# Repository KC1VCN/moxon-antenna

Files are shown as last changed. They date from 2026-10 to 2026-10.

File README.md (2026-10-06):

# 10-Meter Band Moxon Antenna

## Introduction

A Moxon antenna is a two-element beam antenna that uses enhanced capacitive coupling between the driven and parasitic elements. This coupling is achieved by bending the ends of both elements 90&#176; toward each other to form a rectangle. Hence, the antenna is also commonly referred to as a "Moxon Rectangle." Compared with a 2-element Yagi, the Moxon antenna has nearly 25% less width while providing nearly the same amount of gain and an excellent front-to-back ratio. Its input impedance is also naturally close to 50 Ohm. Typically, the bent ends of the elements are connected with insulating rods to complete the rectangle. This provides a more rigid structure and improves stability under wind loading.

The Moxon antenna was invented by Les Moxon, G6XN. A substantial amount of literature is available on the Moxon antenna, and several useful references are listed below:

1. Les Moxon, G6XN, *HF Antennas for All Locations*, Second Edition, Radio Society of Great Britain.

2. L. B. Cebik, W4RNL, *Moxon Rectangles and Online Calculator*, https://antenna2.github.io/cebik/content/moxon/moxpage.html

3. L. B. Cebik, W4RNL, *The Moxon Rectangle: A Review*, https://antenna2.github.io/cebik/content/moxon/mox20.html

4. L. B. Cebik, W4RNL, *An Aluminum 2-Element Moxon Rectangle 10m*, https://antenna2.github.io/cebik/content/moxon/mox.html

5. *The ARRL Antenna Book*, Chapter 13: HF Beam Antennas, page 13.32, 25th Edition.

---

## Construction

In this section, the construction of the antenna is described. Throughout the text, letters shown in parentheses refer to the corresponding reference indicators in the figures or the parts list.

A picture of the antenna is shown in Fig. 1. The antenna is constructed using telescoping aluminum tubes (*a*1, *a*2, *b*1&ndash;*b*4). The low weight and oxidation resistance of aluminum make it an ideal material for HF antenna construction. The driven (*a*1, *b*1, *b*3) and parasitic (*a*2, *b*2, *b*4) elements are held together by a boom made from a square aluminum tube (*c*).

<figure>
  moxon_antenna
  <figcaption><b>Figure 1:</b> 10-meter Moxon antenna.</figcaption>
</figure>

The dimensions of the constructed antenna are given in Fig. 2. The starting point of the design is the example given in *The ARRL Antenna Book*, 25th Edition, page 13-32. Because the diameters and lengths of the aluminum tubes used here differ from those in the published example, the antenna dimensions were adjusted using a full-wave simulator to obtain acceptable return loss and front-to-back far-field ratio in the 10-meter band.

<figure>
  moxon_dimensions
  <figcaption><b>Figure 2:</b> 10-meter Moxon antenna dimensions.</figcaption>
</figure>

A parts list is provided in the repository in both PDF and spreadsheet formats. Two types of parts are required to construct the antenna: parts that can be purchased from online vendors (e.g., tubes and screws), and parts that must be manufactured. For purchased parts, recommended vendors and part numbers are provided. For manufactured parts, the corresponding CAD file names are listed and can be found in the repository. To assist the builder, recommended online vendors capable of manufacturing these parts are also included.

Construction steps are outlined below:

1. Clean all tubes with 90% isopropyl alcohol to remove grease and dirt.
2. Bend the smaller-diameter tubes (*b*1&ndash;*b*4) to obtain the prescribed tail lengths.
3. Cut one of the 6' long larger-diameter tubes (*a*1) in half using a tube cutter. These sections will be used as the left and right driven elements.
4. Cut slits into one end of the larger-diameter tubes (*a*1) using a hacksaw blade.
5. De-burr and lightly smooth all tube ends using a tubing reamer as needed.
6. Prepare the feed assembly, clamp the larger-diameter tubes (*a*1), attach the assembly to the boom, and connect the balun.
7. Prepare the parasitic-element support assembly, clamp the larger-diameter tube (*a*2), and attach it to the boom.
8. Mark the center of the stiffening rod and insert it inside the driven elements until it is symmetric with respect to the feed point.
9. Insert the smaller-diameter tubes (*b*1&ndash;*b*4) into the larger-diameter tubes (*a*1, *a*2) to obtain the prescribed element lengths.
10. Insert the spacer rods into the tail ends and fasten them to the tubes to obtain the prescribed tail gap.
11. Attach the antenna to a mast at its center of gravity using a mast clamp.

> [!NOTE]
> All tube bends should be made using a lever-style tube bender with a 1.5-inch CLR (Center Line Radius). Care must be taken not to crack or collapse the tubes during bending. Therefore, the use of a good-quality lever-style tube bender is important.
>

> [!TIP]
> It is best to carry out the construction on a good, flat surface such as a garage floor.
>

In the following paragraphs, the construction steps are explained in greater detail.

---

### Antenna Feed

This assembly is where the left and right driven elements are connected to the balun terminals and clamped to the boom. Pictures of the antenna feed section are given in Figs. 3 (with balun) and 4 (close-up).

<figure>
  moxonfeed1
  <figcaption><b>Figure 3:</b> Detailed view of the antenna feed (with balun).</figcaption>
</figure>

The left and right driven elements are mounted to a stainless-steel mounting plate (*f*) using polycarbonate tube clamps (*e*) manufactured by FDM (Fused Deposition Modeling). These clamps are bolted down using pan-head screws (*o*) and stainless-steel compression plates (*d*) to provide uniform pressure across the polycarbonate. The screws must be tightened sufficiently to hold the aluminum tubes straight, but they should not be over-tightened. The plate (*f*) is attached to the boom (*c*) using bracket (*j*) and tap bolts (*n*).

The balun plate (*g*) is first attached to the boom using another bracket (*j*) and flat-head screws (*q*). The flat-head screws used to attach the balun plate to the boom bracket are not visible in the picture because they are located under the balun in the final assembly. To ensure that the balun sits flush on the plate, the plate holes should be chamfered to receive the flat-head screws. The 1:1 balun (*h*) is then attached to plate (*g*) using pan-head screws (*r*).

> [!NOTE]
> The height and spacing of the balun terminals should be selected so that, when the balun is mounted, the terminals align with the aluminum-tube contacts as shown in the figures.
>

> [!NOTE]
> The antenna is mounted with the balun facing downward to prevent the accumulation of snow and ice around the feed structure.
>

A 50" long fiberglass stiffener rod (*m*) is inserted inside the larger aluminum tubes from one of the open ends. This stiffener is placed only inside the larger tubes and does not extend into the smaller end tubes. Its purpose is to provide additional mechanical rigidity and damp mechanical oscillations that may occur under wind loading. The rod should be centered to leave sufficient room for the smaller-diameter tubes to slide inside the larger-diameter tubes.

<figure>
  moxon_feed2
  <figcaption><b>Figure 4:</b> Detailed view of the antenna feed (close-up).</figcaption>
</figure>

Contacts for the aluminum tubes are made using 1/2" wide aluminum strips (*k*) wrapped around the tubes to form loop clamps. Connections between the tube contacts and balun terminals are made using the same 1/2" wide aluminum strips (*l*), which are attached to the loop clamps using pan-head screws (*p*). A PVC dielectric (*i*) is placed between the terminal strips (*l*) to lower the impedance closer to 50 Ohm.

The mounting plate (*f*) is attached to the boom (*c*) using a boom bracket (*j*). The same bracket is also used to attach the balun plate (*g*) to the boom.

> [!NOTE]
> The balun shown in the picture is a custom-designed balun housed in a 4"&#xD7;4"&#xD7;2" PVC NEMA box. Similar baluns can be purchased from online stores, and an example is provided in the parts list.
>

The input UHF connector of the balun should be weatherized using self-fusing silicone tape.

> [!NOTE]
> Self-fusing silicone tape does not contain an adhesive for sticking. It should be stretched during application to activate the tape surface and enable self-fusing. After approximately 24 hours, the tape layers will fuse into a single block, providing waterproof insulation.
>

### Parasitic Element Support

This assembly is where the parasitic element is clamped to the boom. A picture of the parasitic-element support is shown in Fig. 5.

<figure>
  moxon_parasitic
  <figcaption><b>Figure 5:</b> Parasitic element support.</figcaption>
</figure>

To keep the driven- and parasitic-element planes aligned, the same mounting approach used for the driven elements is also used here, with polycarbonate tube clamps (*e*) and the stainless-steel mounting plate (*f*).

A polyethylene square plug (*w*) is placed at both ends of the boom to seal the square tube from the elements.

### Tube Connections

This assembly is where the larger-diameter tubes are connected to the smaller-diameter tubes. A picture of the tube connections is shown in Fig. 6.

<figure>
  moxon_tube
  <figcaption><b>Figure 6:</b> Tube connections.</figcaption>
</figure>

The tubes should be cleaned before assembly to remove grease and residue that could otherwise inhibit a good electrical connection. Note that the excess length of the smaller-diameter tubes can remain inside the larger-diameter tubes.

To facilitate the connections, 3/4" long slits are cut along the connecting ends of the larger-diameter tubes (*a*) to receive the smaller-diameter tubes (*b*). Typically, four slits spaced 90 degrees apart are used. In this case, two slits are also sufficient because the smaller-diameter tubes fit snugly inside the larger-diameter tubes; therefore, little flexing of the slitted ends is required. A hacksaw with a blade thickness of 1/32" can be used to make the cuts. Care must be taken to cut the slits as straight as possible.

> [!TIP]
> Cutting straight slits along the length of the tubes can be tricky. The use of a simple jig is recommended, as is practicing first on a disposable piece of aluminum tube.
>

Stainless-steel hose clamps (*y*) are used to compress tubes (*a*) over the slits and secure tube (*b*). The clamps should be tightened while the antenna is resting on a good, flat surface (e.g., a garage floor) to maintain antenna planarity; otherwise, the tube ends may droop.

> [!NOTE]
> Aluminum flashing that is 1" wide and 1/64" thick can be wrapped over the slits before installing the hose clamps to provide resistance to water intrusion. The hose clamps will compress the flashing and the slitted tube together, squeezing the smaller-diameter tube and forming the electrical connection.
>

### Tube-End Spacers

Tube-end spacers are used to keep the ends of the tubes at a precise distance from each other. They also stabilize the antenna rectangle. A picture of the tube-end spacers is shown in Fig. 7.

<figure>
  moxon_coupling
  <figcaption><b>Figure 7:</b> Tube-end spacers.</figcaption>
</figure>

The ends of the tubes (*b*) should be drilled 1.5" from the edge using a 9/64" drill bit, as shown in the figure. A pre-drilled fiberglass rod (*x*) is then inserted inside the tubes, and machine screws (*s*) are used to hold the tubes and rod together. The separation between the drill holes in the rod should be 5.75"+1.5"+1.5" so that, when the rod is inserted into the aluminum tubes and fastened, the gap between the tube ends is exactly 5.75".

> [!TIP]
> To drill the aluminum tubes and rods accurately and perpendicular to their surfaces, a drill guide can be used.
>

---

## Full-wave Electromagnetic Simulations

It is useful to perform full-wave electromagnetic simulations of the antenna structure before assembling the physical antenna. For this purpose, an open-source 3D finite-element solver called Palace (Parallel Large-scale Computational Electromagnetics) was used (https://awslabs.github.io/palace/stable/). Palace has been developed by the Amazon Web Services (AWS) Center for Quantum Computing. The simulation software was installed on a virtual machine (VM) using Microsoft Azure Cloud Computing Services. The simulations were performed on an E4_v4 virtual machine with 4 vCPUs and 32 GB of RAM. One advantage of cloud computing is that the available compute resources, such as RAM and CPU cores, can be scaled according to model complexity.

<figure>
  moxon_model
  <figcaption><b>Figure 8:</b> Aluminum-tube Moxon antenna model showing the simulation parameters.</figcaption>
</figure>

<table style="width: 600px;">
  <caption></caption>
  <thead>
    <tr>
      <th>A1</th>
      <th>A2</th>
      <th>B</th>
      <th>C</th>
      <th>D</th>
      <th>d1</th>
      <th>d2</th>
    </tr>
  </thead>
  <tbody>
    <tr>
      <td>72"</td>
      <td>38.75"</td>
      <td>19.25"</td>
      <td>5.75"</td>
      <td>27.25"</td>
      <td>0.625"</td>
      <td>0.5"</td>
    </tr>
  </tbody>
</table>

The antenna geometry is generated programmatically using a Python script. The script reads the main antenna parameters (*A*1, *A*2, *B*, *C*, *D*) from an Excel worksheet and generates the corresponding mesh files. The mesh files are then used as input to the Palace simulator. The benefit of using a worksheet is that multiple geometry variations can be listed, allowing a simulation to be submitted simply by specifying a row index and thereby enabling automation. The antenna dimensions were optimized to provide good return loss and front-to-back (F/B) far-field ratio over the desired frequency band.

<figure>
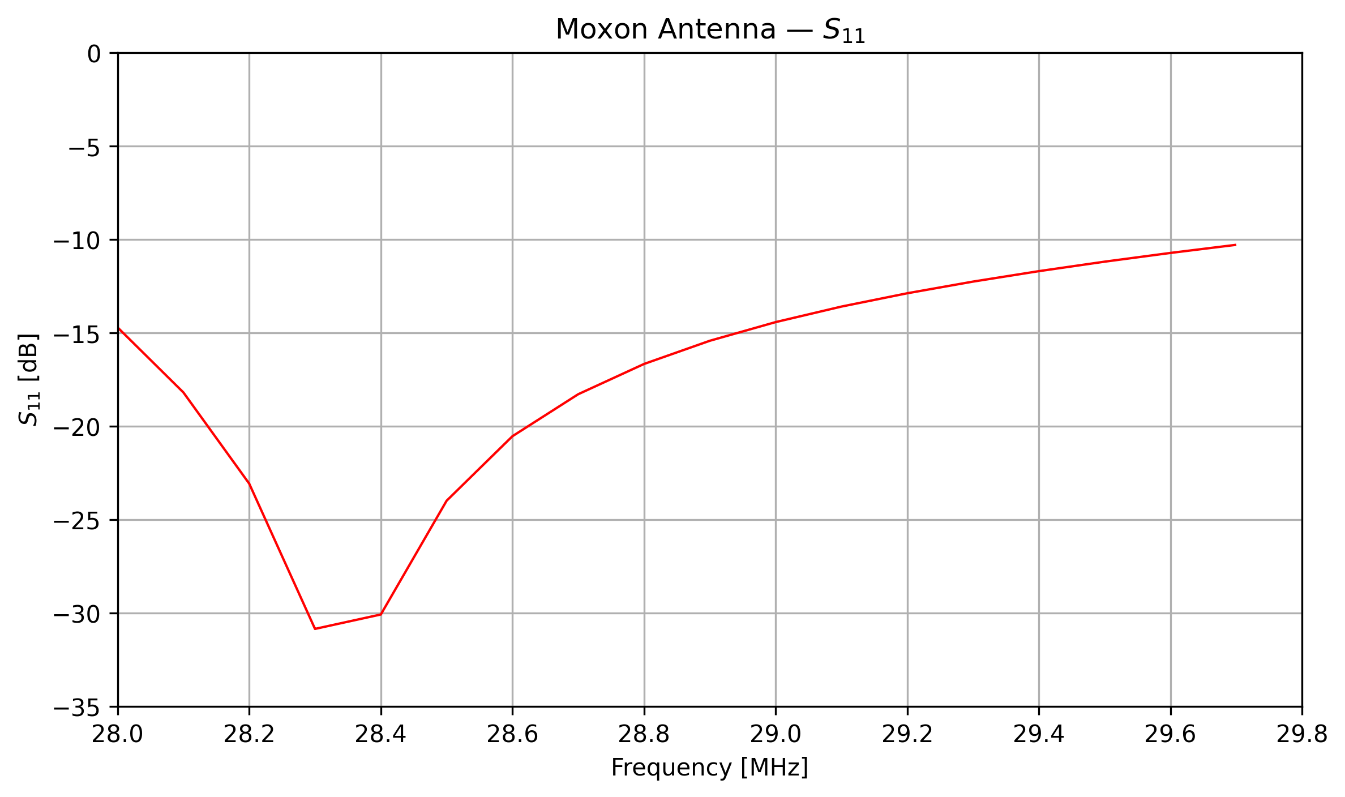
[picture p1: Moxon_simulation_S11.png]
moxon_simulation_S11
  
  <figcaption><b>Figure 9:</b> Simulated S<sub>11</sub> of the 10-meter Moxon antenna.</figcaption>
</figure>

<figure>
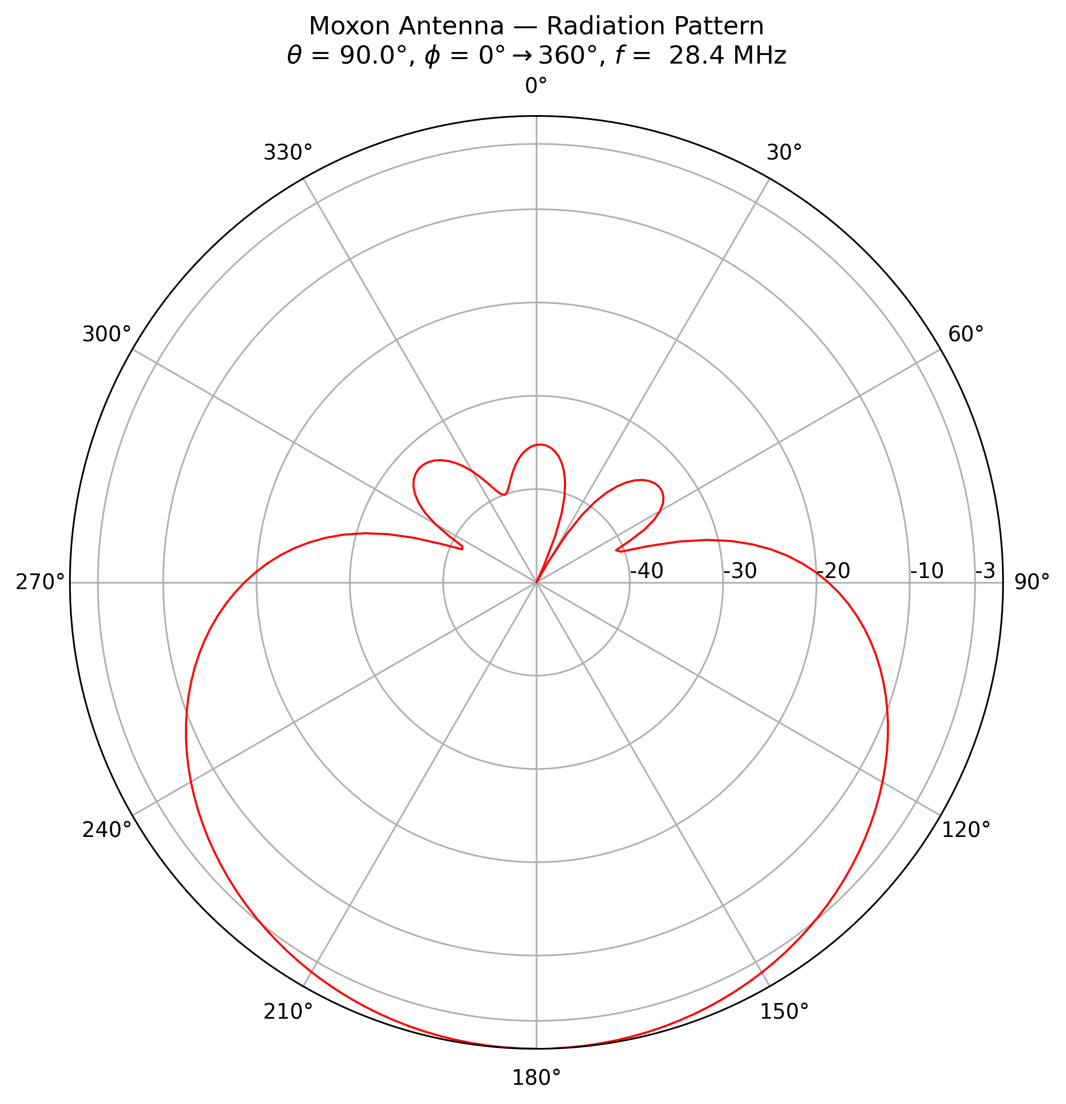
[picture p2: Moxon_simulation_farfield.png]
moxon_simulation_farfield
  
  <figcaption><b>Figure 10:</b> Simulated normalized far-field of the 10-meter Moxon antenna.</figcaption>
</figure>

---

## Measurement Results

The measured return loss (*S*<sub>11</sub>) of the antenna is shown in Fig. 11. The measurements were made using a network analyzer while the antenna was mounted approximately 23 feet above ground on a fiberglass push-up pole. The measurement setup was located at the bottom of the pole. Therefore, the results include the effects of the connecting RG-8X coaxial cable, RF connectors, and the 1:1 balun. A more accurate characterization of the antenna itself could be obtained if the balun were characterized and tuned separately; however, time and resource limitations did not allow this.

<figure>
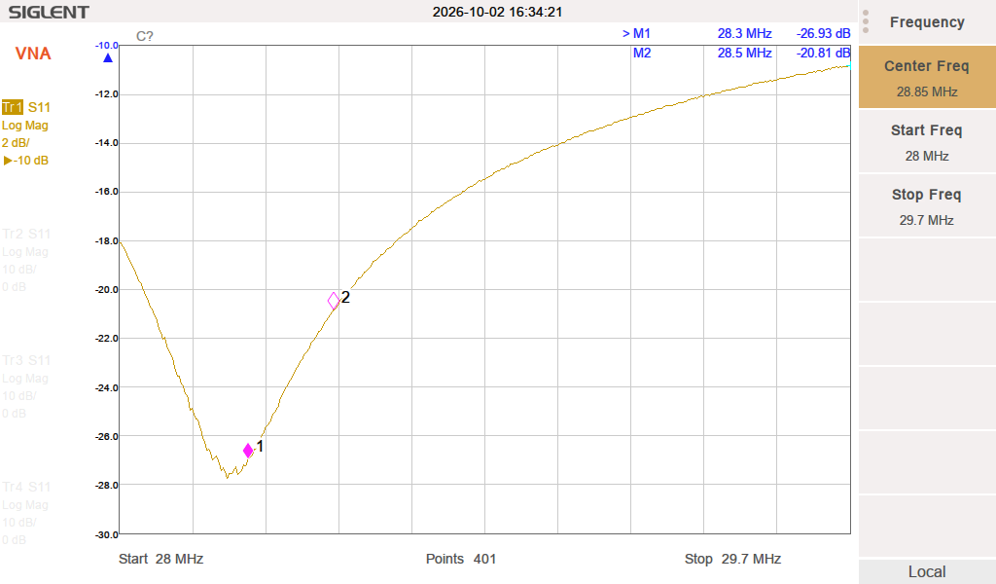
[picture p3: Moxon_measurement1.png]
moxon_measurement1
  
  <figcaption><b>Figure 11:</b> Measured S<sub>11</sub> of the 10-meter Moxon antenna.</figcaption>
</figure>

The return loss of the antenna is excellent between 28.3 and 28.5 MHz, which is the portion of the 10-meter band reserved for technician-class SSB phone communications in the U.S. If desired, the return-loss minimum can be shifted to another portion of the band by re-optimizing the dimensions. Note that, although the return loss is relatively broadband across the band, the front-to-back ratio is more sensitive to operating frequency.

A comparison of the simulated and measured antenna responses is shown in Fig. 12. As can be seen from the plots, the measurement and simulation agree relatively well. The discrepancy around the *S*<sub>11</sub> dip can be attributed to the effects of the balun and feed structure.

<figure>
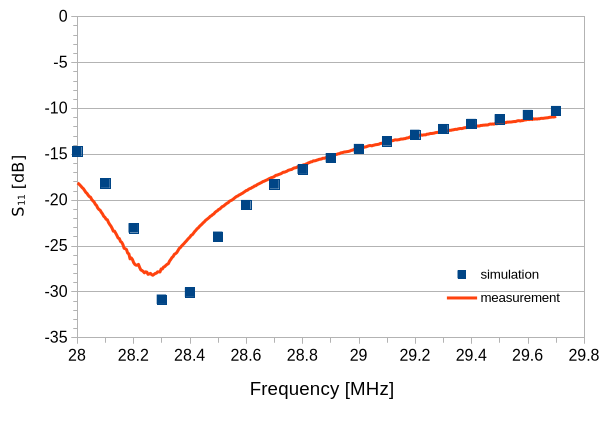
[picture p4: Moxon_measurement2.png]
moxon_measurement2
  
  <figcaption><b>Figure 12:</b> Simulation vs. measurement of the 10-meter Moxon antenna.</figcaption>
</figure>

---

## License

The hardware design, geometry-generation source code, simulation input files, and other source material in this repository are licensed under the **CERN Open Hardware Licence Version 2 – Weakly Reciprocal (CERN-OHL-W-2.0)**, unless otherwise noted.

Commercial use is permitted under the terms of CERN-OHL-W-2.0. Modified Covered Source must retain the applicable Notices and include the modification notice required by the license, including the date and a brief description of the modifications. Products made using the Covered Source must provide the Complete Source or identify the Source Location as required by the license.

The full license text is provided in the [`LICENSE`](LICENSE) file, and project-specific attribution and Source Location information are provided in the [`NOTICE`](NOTICE) file.

Third-party software used with this project, including Palace and Gmsh, is not part of the Covered Source in this repository and remains subject to its respective license.

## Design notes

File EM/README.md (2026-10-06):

# 10-Meter Band Moxon Antenna

## Full-wave Electromagnetic Simulations

This section explains the full-wave electromagnetic simulation of the 10-meter Moxon antenna using `Palace` (Parallel Large-scale Computational Electromagnetics), a finite-element-method (FEM) simulator. Palace has been developed by the Amazon Web Services (AWS) Center for Quantum Computing (https://awslabs.github.io/palace/stable/). It is an open-source software licensed under Apache-2.0 and may be used for both non-commercial and commercial applications.

The full-wave electromagnetic simulation of the Moxon antenna using `Palace` consists of two distinct steps: mesh generation and FEM simulation using the generated mesh. Python scripts are provided to simplify each task. The name and description of each script are given in the following table:

<table style="width: 600px;">
  <caption></caption>
  <thead>
    <tr style="background-color: white;">
      <th>Script Name</th>
      <th>Description</th>
    </tr>
  </thead>
  <tbody>
    <tr style="background-color: white;">
      <td>moxon_mesh.py</td>
      <td>Geometry and mesh generator for the Moxon antenna</td>
    </tr>
     <tr style="background-color: white;">
      <td>moxon_run.py</td>
      <td>Simulator launcher for the Moxon antenna</td>
    </tr>
    <tr style="background-color: white;">
      <td>mesh_info.py</td>
      <td>Mesh checker and attribute reader</td>
    </tr>
  </tbody>
</table>

The mesh-generation script is designed to read the antenna parameters from an Excel spreadsheet. To simulate a Moxon antenna, the user first enters the desired geometrical parameters into an Excel worksheet. As many parameter combinations as desired can be entered. Each combination is referenced by a unique index number in the spreadsheet. The antenna mesh can then be generated for a particular combination using its corresponding index number, after which the FEM simulation can be run using the generated mesh.

This approach provides flexibility for automation. For example, multiple geometric variations can be simulated overnight by first entering the parameter values into the spreadsheet, generating the mesh files, and then sweeping the corresponding indices in a Bash loop to run the simulator.

Installation and operating instructions are given below. These steps have been tested on AlmaLinux 9.8, although they should work on other Linux distributions with little or no modification.

---

## Installing Palace

### Step 1 – Install Spack

`Spack` is a package manager designed for scientific and high-performance-computing software (https://spack.io/). It simplifies the installation and management of scientific software and allows multiple versions of a package to be installed and selected as needed. Here, Spack is used to install the `Palace` simulator.

Installation of `Palace` requires certain system-level packages to be present. Therefore, first install the following packages with `root` privileges:

```bash
sudo dnf install git
sudo dnf install gcc gcc-c++ gcc-gfortran
sudo dnf install lbzip2
sudo dnf install bzip2
sudo dnf install patch
sudo dnf install unzip
```

Then, install and activate `Spack` as follows. Spack can be installed by a regular user, and doing so is recommended:

```bash
git clone -c feature.manyFiles=true https://github.com/spack/spack.git

source ~/spack/share/spack/setup-env.sh
```

### Step 2 – Install Palace

Once `Spack` is installed and activated, `Palace` and its required dependencies can be installed using the following command:

```bash
spack install palace
```

After installation, `Palace` should be loaded before use:

```bash
spack load palace
```

### Step 3 – Test the Installation

After loading `Palace`, run the following command to verify the installation:

```bash
palace --help
```

You should see the help output from the simulator. The next step is to download and run a simple test case:

```bash
mkdir -p ~/palace-test/mesh
cd ~/palace-test

curl -o mesh/spheres.msh https://raw.githubusercontent.com/awslabs/palace/refs/heads/main/examples/spheres/mesh/spheres.msh
curl -O https://raw.githubusercontent.com/awslabs/palace/refs/heads/main/examples/spheres/spheres.json

palace --dry-run spheres.json
```

If the dry-run does not report any errors, proceed with the full simulation:

```bash
palace -np 1 spheres.json
```

The simulation should start by displaying the `Palace` banner and other relevant information. The model consists of two conducting spheres with radii of 1 cm and 2 cm, separated by 5 cm in vacuum and surrounded by a distant grounded boundary. Palace computes the Maxwell capacitance matrix using a third-order finite-element solution.

Once the simulation is complete, inspect the `terminal-C.csv` file in the `postpro` directory. You should obtain capacitance values close to the following, together with the corresponding analytical values:

<table style="width: 600px;">
  <caption></caption>
  <thead>
    <tr style="background-color: white;">
      <th>Parameter</th>
      <th>Palace Simulation [pF]</th>
      <th>Analytical Value [pF]</th>
    </tr>
  </thead>
  <tbody>
    <tr style="background-color: white;">
      <td>C<sub>11</sub></td>
      <td>1.23745</td>
      <td>1.23052</td>
    </tr>
    <tr style="background-color: white;">
      <td>C<sub>22</sub></td>
      <td>2.47841</td>
      <td>2.43154</td>
    </tr>
    <tr style="background-color: white;">
      <td>C<sub>12</sub></td>
      <td>-0.4771</td>
      <td>-0.4946</td>
    </tr>
  </tbody>
</table>

---

## Running Palace

### Step 1 – Set Up a Python Virtual Environment

It is recommended to use a Python virtual environment for running the provided Python scripts. To create the environment, first ensure that Python 3.12 is installed on the operating system:

```bash
sudo dnf install python3.12
```

Then, proceed as follows from a terminal:

```bash
python3.12 -m venv ~/.palace01
source ~/.palace01/bin/activate
pip install --upgrade pip
pip install xlrd
pip install gmsh
```

### Step 2 – Activate the Python Virtual Environment

The environment is already active immediately after the creation step above. For subsequent simulation sessions, activate it again as follows:

```bash
source ~/.palace01/bin/activate
```

### Step 3 – Update the Moxon.xls File

Open the provided `Moxon.xls` template and enter the desired parameter combinations. The Moxon antenna parameters used by the script are shown in Fig. 1. You may enter as many combinations as desired. Be sure to assign a unique index number to each combination. After entering the parameters, save the file.

<figure>
  Moxon_model
  <figcaption><b>Figure 1:</b> Aluminum-tube Moxon antenna model showing the simulation parameters.</figcaption>
</figure>

### Step 4 – Generate the Antenna Model and Mesh

Generate the antenna geometry and mesh file using the following command:

```bash
./moxon_mesh.py 001
```

The script takes the index number of the desired parameter combination as a command-line argument. In the example above, the model and mesh are generated for index `001`. Once complete, the script creates a directory with the same name as the index and saves a mesh file (`.msh`) and a stereolithography file (`.stl`) in that directory. The `.msh` file is used by the Palace simulator. The `.stl` file can be opened with a CAD editor to inspect the generated model.

Note that the `.stl` file contains the mesh triangles, and the air volume surrounding the antenna may therefore obscure the antenna elements. To visualize the antenna elements, it may be necessary to explode the model into its mesh groups and make the surrounding air volume invisible in the CAD tool.

You may also verify the integrity of the generated mesh and read the embedded design attributes using the following script:

```bash
./mesh_info.py ./001/moxon.msh
```

The mesh-generation script embeds the parameter values used to generate the antenna model in the mesh file as design attributes. This is useful when the parameter values associated with a particular mesh file need to be identified later.

### Step 5 – Simulate the Antenna

Once the mesh is ready, generate the JSON configuration file that describes the model and simulation parameters using the provided template, and perform a dry-run:

```bash
source ~/spack/share/spack/setup-env.sh
spack load palace

./moxon_run.py 001 1 1
```

The first command-line argument is the index number. The second argument instructs the script to generate JSON configuration file, and the last argument instructs it to perform a dry-run to check the JSON file.

The JSON configuration file contains information required to describe the model, including material properties, frequency range, and desired output files. The script copies a template to create a local JSON configuration file in the simulation directory, which has the same name as the index. Simulation parameters may then be modified by directly editing this local file. For subsequent runs, set the second command-line argument to zero to avoid overwriting the modified local configuration file.

If the JSON configuration passes the dry-run, proceed with simulation using the following command:

```bash
./moxon_run.py 001 0 0
```

Because the JSON file has already been created and verified by the dry-run, the last two arguments are zero in this case. The simulation should start and proceed through the specified frequency sweep.

> [!NOTE]
> Using the mesh settings in the script, the simulation of the 10-meter Moxon antenna reaches a peak memory usage of approximately 22.7 GB. This should not be interpreted as the minimum memory required for the problem; further optimization of the mesh may reduce memory consumption while maintaining comparable simulation accuracy.
>

If many parameter combinations are to be simulated overnight, a Bash loop similar to the following can be used (assuming the corresponding mesh files are generated in advance):

```bash
for i in $(seq -w 001 010); do
    ./moxon_run.py "$i" 0 0
done
```

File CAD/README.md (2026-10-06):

# 10-Meter Band Moxon Antenna

## CAD Files

This section contains the CAD files required to manufacture the custom parts used in the antenna assembly.

`FreeCAD` source files are provided for all custom parts and should be considered the primary editable design files. DXF and STL exports are also included for convenience and manufacturing reference.

The DXF files are intended primarily for 2D fabrication processes, while the STL files may be used for 3D printing or for viewing the part geometry in compatible software.

Images of the completed parts are provided below to illustrate their expected appearance after manufacturing.

Unless otherwise noted, dimensions and geometry should be taken from the `FreeCAD` source files.

---

<figure>
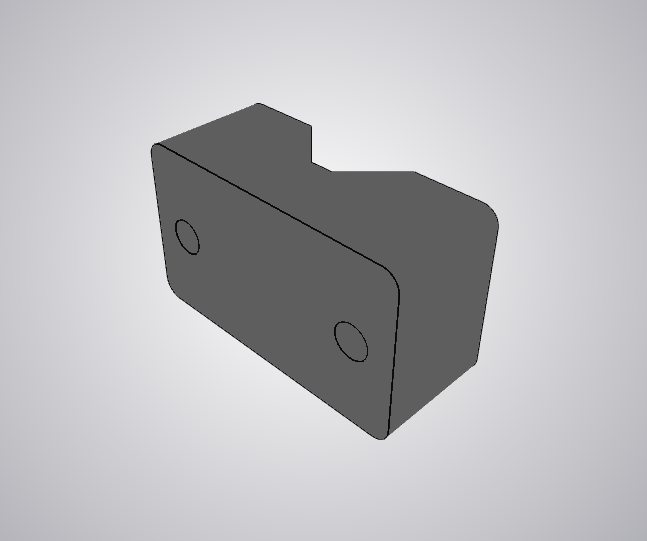
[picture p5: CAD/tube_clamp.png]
tube_clamp
  
  <figcaption>Tube clamp (e)</figcaption>
</figure>

---

<figure>
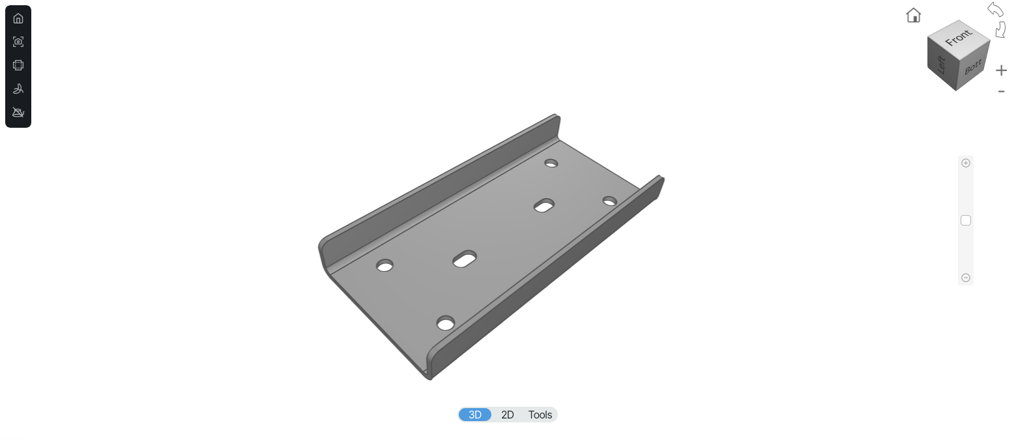
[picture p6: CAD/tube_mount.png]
tube_mount
  
  <figcaption>Tube mounting plate (f)</figcaption>
</figure>

---

<figure>
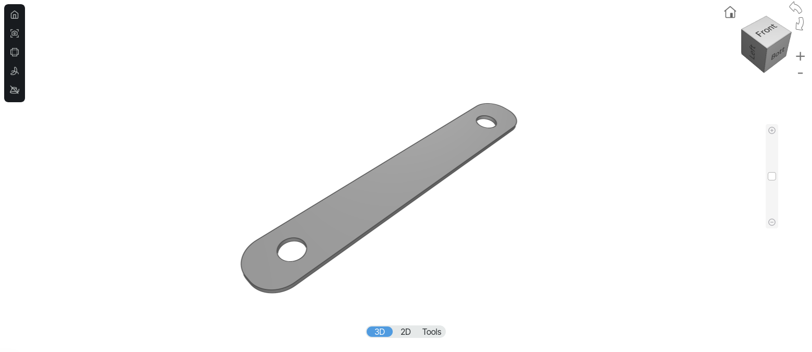
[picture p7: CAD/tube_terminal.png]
tube_terminal
  
  <figcaption>Tube and Balun terminals (k, l)</figcaption>
</figure>

---

<figure>
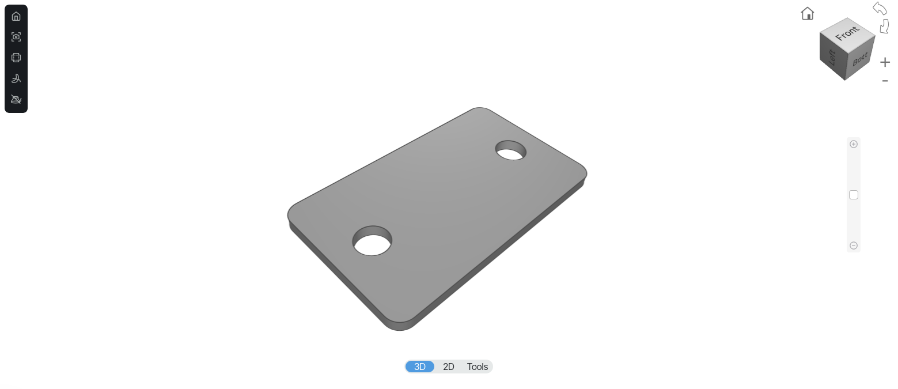
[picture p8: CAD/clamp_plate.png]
clamp_plate
  
  <figcaption>Clamp plate (d)</figcaption>
</figure>

---

<figure>
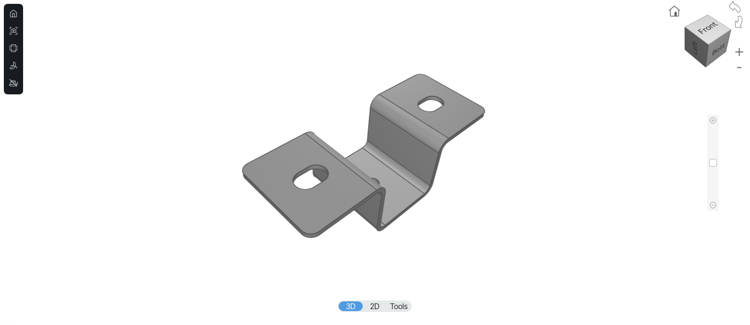
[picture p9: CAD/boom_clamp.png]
boom_clamp
  
  <figcaption>Boom clamp (j)</figcaption>
</figure>

---

<figure>
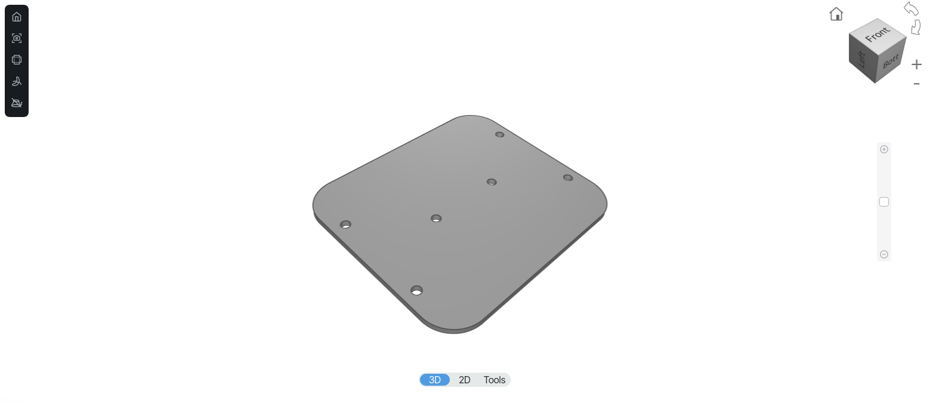
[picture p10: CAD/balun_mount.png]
balun_mount
  
  <figcaption>Balun mounting plate (g)</figcaption>
</figure>

---

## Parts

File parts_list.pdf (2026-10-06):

Reference Description | Vendor | | Quantity
a1-a2 | onlinemetals.com | 19596 | 2
b1-b4 | onlinemetals.com | 1210 | 4
c | onlinemetals.com | 1191 | 1
d | sendcutsend.com | clamp_plate.dxf | 4
e | craftcloud.com | tube_clamp.stl | 8
f | sendcutsend.com | tube_mount.dxf | 2
g | sendcutsend.com | balun_mount.dxf | 1
h | dxengineering.com | DXE-MC20-1-1 | 1
i | mcmaster.com | 8740K121 | 1
j | sendcutsend.com | boom_clamp.dxf | 3
k | sendcutsend.com | tube_terminal.dxf | 2
l | sendcutsend.com | tube_terminal.dxf | 2

Part Number/
File Name

round tube
aluminum, 6061-T6-drawn, ASTM-B210, 5/8" OD
✕ | ✕ 0.058" Wall | 0.509" ID, 6' long
round tube
aluminum, 6061-T6-drawn, ASTM-B210, 1/2" OD
✕ | ✕ 0.065" Wall | 0.370" ID, 6' long
square tube
aluminum, 6063-T52-extruded, ASTM-B221, 3/4" Height 0.065" Wall, 6' long ✕ clamp plate
stainless steel 304, 0.074" thick
tube clamp
Polycarbonate (FDM), 80% Gyroid infill, black
tube mounting plate
stainless steel 304, 0.074" thick balun mounting plate
ABS, 0.125" thick, black
Balun
1:1 impedance ratio, 50 Ohm, 2-50 MHz
4" | 4" | 2" NEMA Type 6P PVC Box ✕ | ✕
1" terminal spacing, 1/4" terminal bolt insulator bar
chemical-resistant PVC, 1/4" thick, 1" wide, extruded, gray
boom clamp
stainless steel 304, 0.048" thick tube terminal
aluminum 5052-H32, 0.040" thick balun terminal
aluminum 5052-H32, 0.040" thick
| A | B | C | D | E

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
m | mcmaster.com | 8543K51

1

n | boltdepot.com | 5623

4

o | boltdepot.com | 9655

8

p | boltdepot.com | 1356

2

q | boltdepot.com | 1258

2

r | boltdepot.com | 1348

4

s | boltdepot.com | 1338

4

w | mcmaster.com | 9565K5

2

x | mcmaster.com | 8669K569

2

y | mcmaster.com | 54155K11

4

- | boltdepot.com | 2552 | 14 - | boltdepot.com | 2551 | 4

stiffening rod
structural FRP fiberglass, 1/2" diameter, reinforcement: fiberglass fabric, resin: Polyester plastic, white, 5' long
tap bolt
stainless steel 18-8, #10-24, 3/4" machine screw
Phillips pan head, stainless steel 18-8, #10-24, 2-1/4"
machine screw
Phillips pan head, stainless steel 18-8, #10-24, 1/2"
machine screw
Phillips flat head, stainless steel 18-8, #10-24, 1/2"
machine screw
Phillips pan head, stainless steel 18-8, #8-32, 3/4"
machine screw
Phillips pan head, stainless steel 18-8, #6-32, 3/4"
tube end cap
Polyethylene, 0.6" to 0.67" inside size, square, black
spacer rod
flame-retardant Garolite G-10/FR4, 5/16" diameter, reinforcement: fiberglass fabric, resin: epoxy, orange, 1' long
hose clamp
stainless-steel material 301, stainless-steel housing 301, stainless-steel screw 305, 7/16" to 25/32" range, 1/2" width, worm-drive
hex nylon-insert lock nut
stainless steel 18-8, #10-24
hex nylon-insert lock nut
stainless steel 18-8, #8-32
| A | B | C | D | E

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
- | boltdepot.com | 2550

4

- | boltdepot.com | 2560

2

- | boltdepot.com | 2946 | 24 - | boltdepot.com | 2943 | 8 - | boltdepot.com | 2942 | 8 - | mcmaster.com | 7643A79 | 1 - | grainger.com | 3KE42 | 1 - | grainger.com | 24C982 | 1 - | grainger.com | 6XW70 | 1 - | grainger.com | 3ARC7 | 1 - | mcmaster.com | 9550T14 | 1

hex nylon-insert lock nut
stainless steel 18-8, #6-32 hex nut
stainless steel 18-8, #10-24 flat washer
stainless steel 18-8, #10
flat washer
stainless steel 18-8, #8
flat washer
stainless steel 18-8, #6
self-fusing electrical tape
silicone rubber, 1" wide, 0.012" thick tube bender
lever-style tube bender for soft metal, for tube OD: 1/2", bend radius: 1 1/2"
hacksaw blade
bi-metal blade, 24 TPI, 1/32" blade thickness, 1/2" blade width
tube cutter
for aluminum and copper, 1/4" – 1 1/8" OD cutting capacity
tubing reamer
tube inner/outer reamer, copper/stainless steel, max. pipe OD: 1-1/4", min. pipe OD: 1/4"
drill bit guide
for drill bit size 1/8", 9/64", 5/32", 11/64", 3/16", 13/64", 7/32", 15/64", 1/4", 17/64", 9/32", 19/64", 5/16", 21/64", 11/32", 23/64", 3/8"
| A | B | C | D | E

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
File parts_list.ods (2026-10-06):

Reference | Description | Vendor | Part Number/ File Name | Quantity
a1-a2 | round tube aluminum, 6061-T6-drawn, ASTM-B210, 5/8" OD ✕ 0.058" Wall ✕ 0.509" ID, 6' long | onlinemetals.com | 19596 | 2
b1-b4 | round tube aluminum, 6061-T6-drawn, ASTM-B210, 1/2" OD ✕ 0.065" Wall ✕ 0.370" ID, 6' long | onlinemetals.com | 1210 | 4
c | square tube aluminum, 6063-T52-extruded, ASTM-B221, 3/4" Height ✕ 0.065" Wall, 6' long | onlinemetals.com | 1191 | 1
d | clamp plate stainless steel 304, 0.074" thick | sendcutsend.com | clamp_plate.dxf | 4
e | tube clamp Polycarbonate (FDM), 80% Gyroid infill, black | craftcloud.com | tube_clamp.stl | 8
f | tube mounting plate stainless steel 304, 0.074" thick | sendcutsend.com | tube_mount.dxf | 2
g | balun mounting plate ABS, 0.125" thick, black | sendcutsend.com | balun_mount.dxf | 1
h | Balun 1:1 impedance ratio, 50 Ohm, 2-50 MHz 4" ✕ 4" ✕ 2" NEMA Type 6P PVC Box 1" terminal spacing, 1/4" terminal bolt | dxengineering.com | DXE-MC20-1-1 | 1
i | insulator bar chemical-resistant PVC, 1/4" thick, 1" wide, extruded, gray | mcmaster.com | 8740K121 | 1
j | boom clamp stainless steel 304, 0.048" thick | sendcutsend.com | boom_clamp.dxf | 3
k | tube terminal aluminum 5052-H32, 0.040" thick | sendcutsend.com | tube_terminal.dxf | 2
l | balun terminal aluminum 5052-H32, 0.040" thick | sendcutsend.com | tube_terminal.dxf | 2
m | stiffening rod structural FRP fiberglass, 1/2" diameter, reinforcement: fiberglass fabric, resin: Polyester plastic, white, 5' long | mcmaster.com | 8543K51 | 1
n | tap bolt stainless steel 18-8, #10-24, 3/4" | boltdepot.com | 5623 | 4
o | machine screw Phillips pan head, stainless steel 18-8, #10-24, 2-1/4" | boltdepot.com | 9655 | 8
p | machine screw Phillips pan head, stainless steel 18-8, #10-24, 1/2" | boltdepot.com | 1356 | 2
q | machine screw Phillips flat head, stainless steel 18-8, #10-24, 1/2" | boltdepot.com | 1258 | 2
r | machine screw Phillips pan head, stainless steel 18-8, #8-32, 3/4" | boltdepot.com | 1348 | 4
s | machine screw Phillips pan head, stainless steel 18-8, #6-32, 3/4" | boltdepot.com | 1338 | 4
w | tube end cap Polyethylene, 0.6" to 0.67" inside size, square, black | mcmaster.com | 9565K5 | 2
x | spacer rod flame-retardant Garolite G-10/FR4, 5/16" diameter, reinforcement: fiberglass fabric, resin: epoxy, orange, 1' long | mcmaster.com | 8669K569 | 2
y | hose clamp stainless-steel material 301, stainless-steel housing 301, stainless-steel screw 305, 7/16" to 25/32" range, 1/2" width, worm-drive | mcmaster.com | 54155K11 | 4
- | hex nylon-insert lock nut stainless steel 18-8, #10-24 | boltdepot.com | 2552 | 14
- | hex nylon-insert lock nut stainless steel 18-8, #8-32 | boltdepot.com | 2551 | 4
- | hex nylon-insert lock nut stainless steel 18-8, #6-32 | boltdepot.com | 2550 | 4
- | hex nut stainless steel 18-8, #10-24 | boltdepot.com | 2560 | 2
- | flat washer stainless steel 18-8, #10 | boltdepot.com | 2946 | 24
- | flat washer stainless steel 18-8, #8 | boltdepot.com | 2943 | 8
- | flat washer stainless steel 18-8, #6 | boltdepot.com | 2942 | 8
- | self-fusing electrical tape silicone rubber, 1" wide, 0.012" thick | mcmaster.com | 7643A79 | 1
- | tube bender lever-style tube bender for soft metal, for tube OD: 1/2", bend radius: 1 1/2" | grainger.com | 3KE42 | 1
- | hacksaw blade bi-metal blade, 24 TPI, 1/32" blade thickness, 1/2" blade width | grainger.com | 24C982 | 1
- | tube cutter for aluminum and copper, 1/4" – 1 1/8" OD cutting capacity | grainger.com | 6XW70 | 1
- | tubing reamer tube inner/outer reamer, copper/stainless steel, max. pipe OD: 1-1/4", min. pipe OD: 1/4" | grainger.com | 3ARC7 | 1
- | drill bit guide for drill bit size 1/8", 9/64", 5/32", 11/64", 3/16", 13/64", 7/32", 15/64", 1/4", 17/64", 9/32", 19/64", 5/16", 21/64", 11/32", 23/64", 3/8" | mcmaster.com | 9550T14 | 1

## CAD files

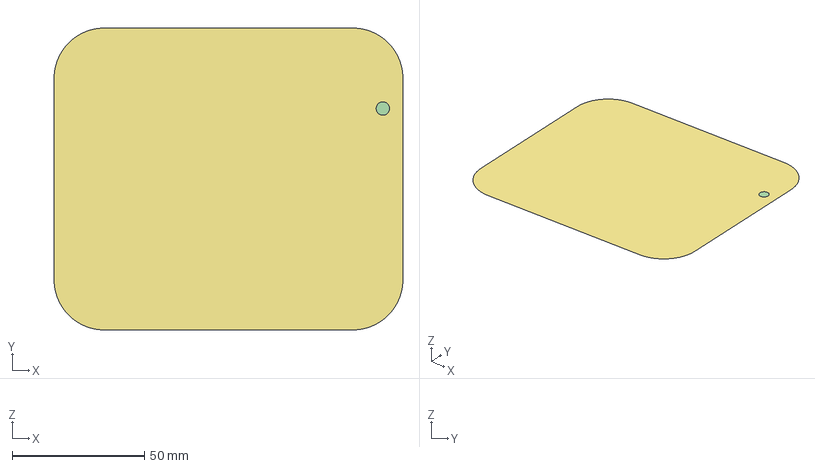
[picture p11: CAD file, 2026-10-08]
CAD/balun_mount.FCStd
132.1 x 114.3 x 0 mm
Circle001
Circle002
Circle003
Circle004
Circle005
Circle006
Rectangle

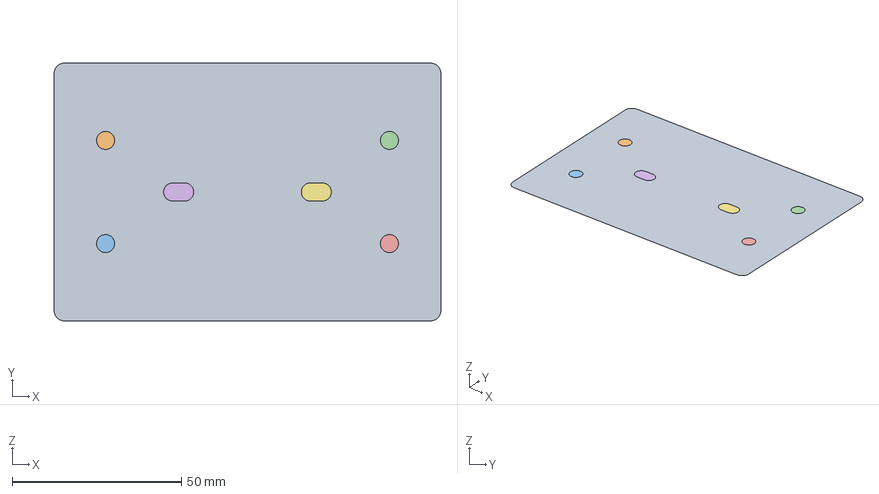
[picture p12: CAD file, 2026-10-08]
CAD/tube_mount.FCStd
114.3 x 76.2 x 0 mm
Rectangle001
Circle001
Circle002
Circle003
Circle004
Rectangle005
Rectangle006

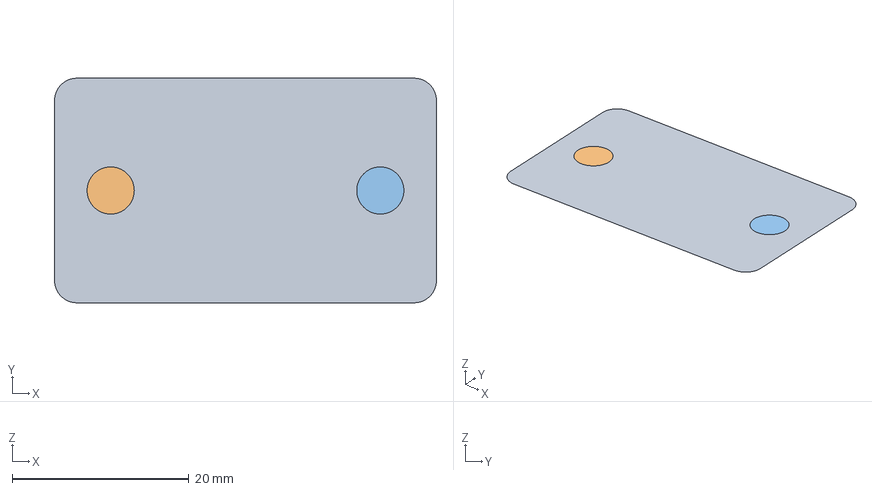
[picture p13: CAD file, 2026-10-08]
CAD/clamp_plate.FCStd
43.2 x 25.4 x 0 mm
Rectangle001
Circle001
Circle002

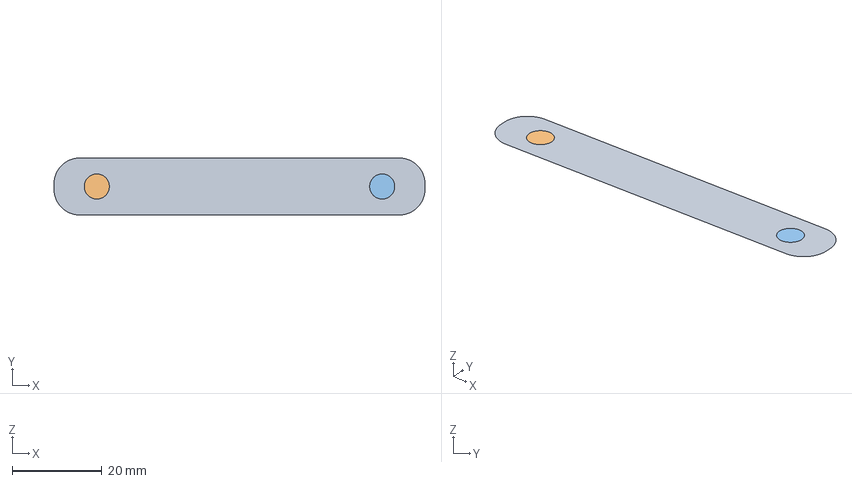
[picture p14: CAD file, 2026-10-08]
CAD/tube_terminal.FCStd
82.5 x 12.7 x 0 mm
Rectangle001
Circle001
Circle002

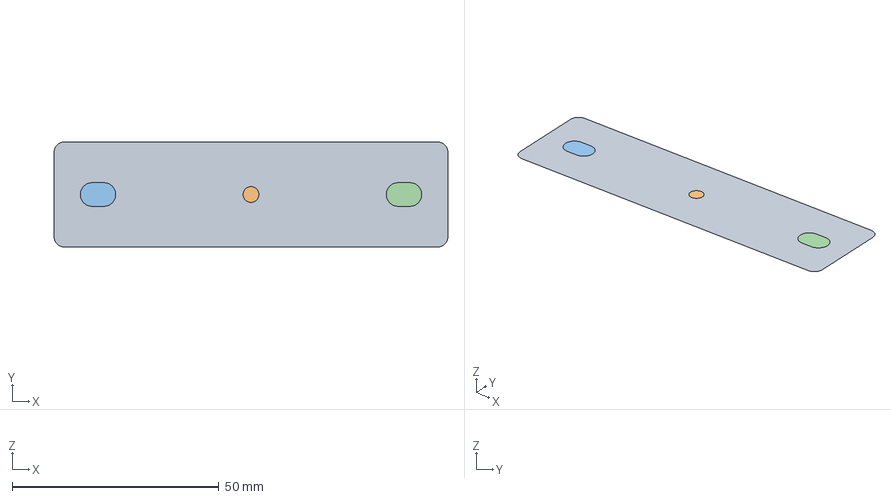
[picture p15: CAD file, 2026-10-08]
CAD/boom_clamp.FCStd
95.2 x 25.4 x 0 mm
Rectangle001
Circle003
Rectangle002
Rectangle003

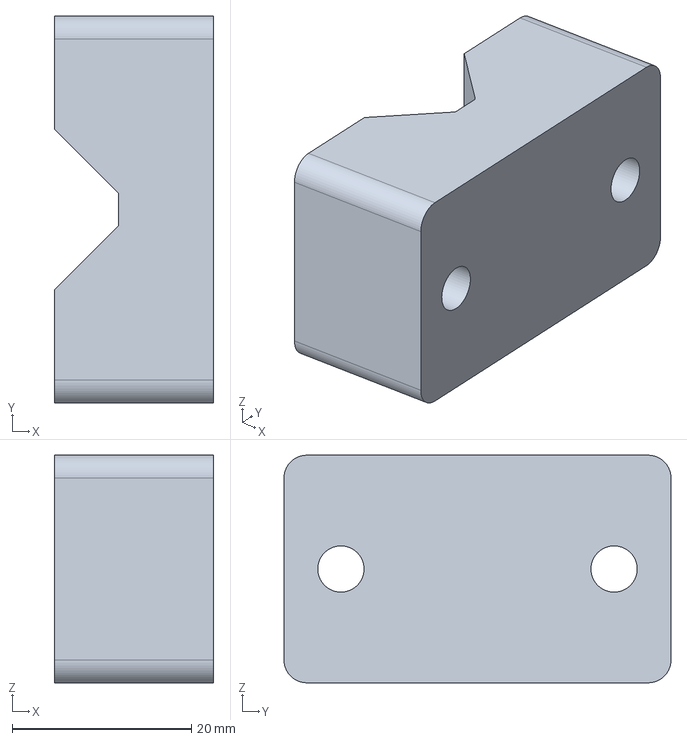
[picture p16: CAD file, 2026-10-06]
CAD/tube_clamp.FCStd
17.8 x 43.2 x 25.4 mm

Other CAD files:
CAD/balun_mount.dxf
CAD/boom_clamp.dxf
CAD/clamp_plate.dxf
CAD/tube_clamp.stl
CAD/tube_mount.dxf
CAD/tube_terminal.dxf
